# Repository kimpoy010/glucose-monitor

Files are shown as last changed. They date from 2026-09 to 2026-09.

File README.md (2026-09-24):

# Glucose Monitor (ESP32-C3, sweat + urine, DIY biosensor)

**⚠️ Not a medical device.** This is a research/educational electrochemical
biosensor rig. Sweat and urine glucose do NOT reliably track blood glucose
(see "Limitations" below). Do not use it to make insulin or treatment decisions.

## What this measures

Two independent electrochemical channels, each a 2-electrode amperometric
glucose oxidase (GOx) enzyme sensor read through a **discrete op-amp
transimpedance amplifier (TIA)** — no potentiostat AFE IC, no external ADC.
This is the cheapest working version of the build.

- **Sweat channel** — GOx electrode → op-amp TIA → ESP32-C3 ADC (GPIO0)
- **Urine channel** — GOx electrode → op-amp TIA → ESP32-C3 ADC (GPIO1)

The GOx enzyme oxidizes glucose and produces a small current proportional
(roughly, over a limited range) to glucose concentration. Each TIA converts
that current to a voltage the ESP32-C3's ADC can read directly.

## Hardware / BOM

| Part | Approx. cost | Notes |
|---|---|---|
| ESP32-C3 dev board | $3–5 | |
| 2x op-amp (LM358 or MCP6002, dual/single-supply, low bias current) | $0.30–1 each | one per channel |
| Feedback resistors (Rf, start ~100 kΩ–1 MΩ) | ~$1 | tune per electrode's current range |
| Bias divider resistors (2x per channel, e.g. 10 kΩ/10 kΩ off VCC) | ~$1 | sets working point at VCC/2 |
| Breadboard + jumper wires | $3–5 | |
| 2x GOx enzyme electrode/strip (salvaged from cheap glucose test strips, or bare screen-printed electrodes) | $0.20–0.50 each | working + reference/counter leads tied per the circuit below |
| SSD1306 0.96" I2C OLED (128x64) | $3–6 | displays both readings; shares the I2C bus (SDA/SCL) |

Total new spend: roughly **$11–20** if you don't already have a breadboard
and passive-component kit.

## Circuit (per channel)

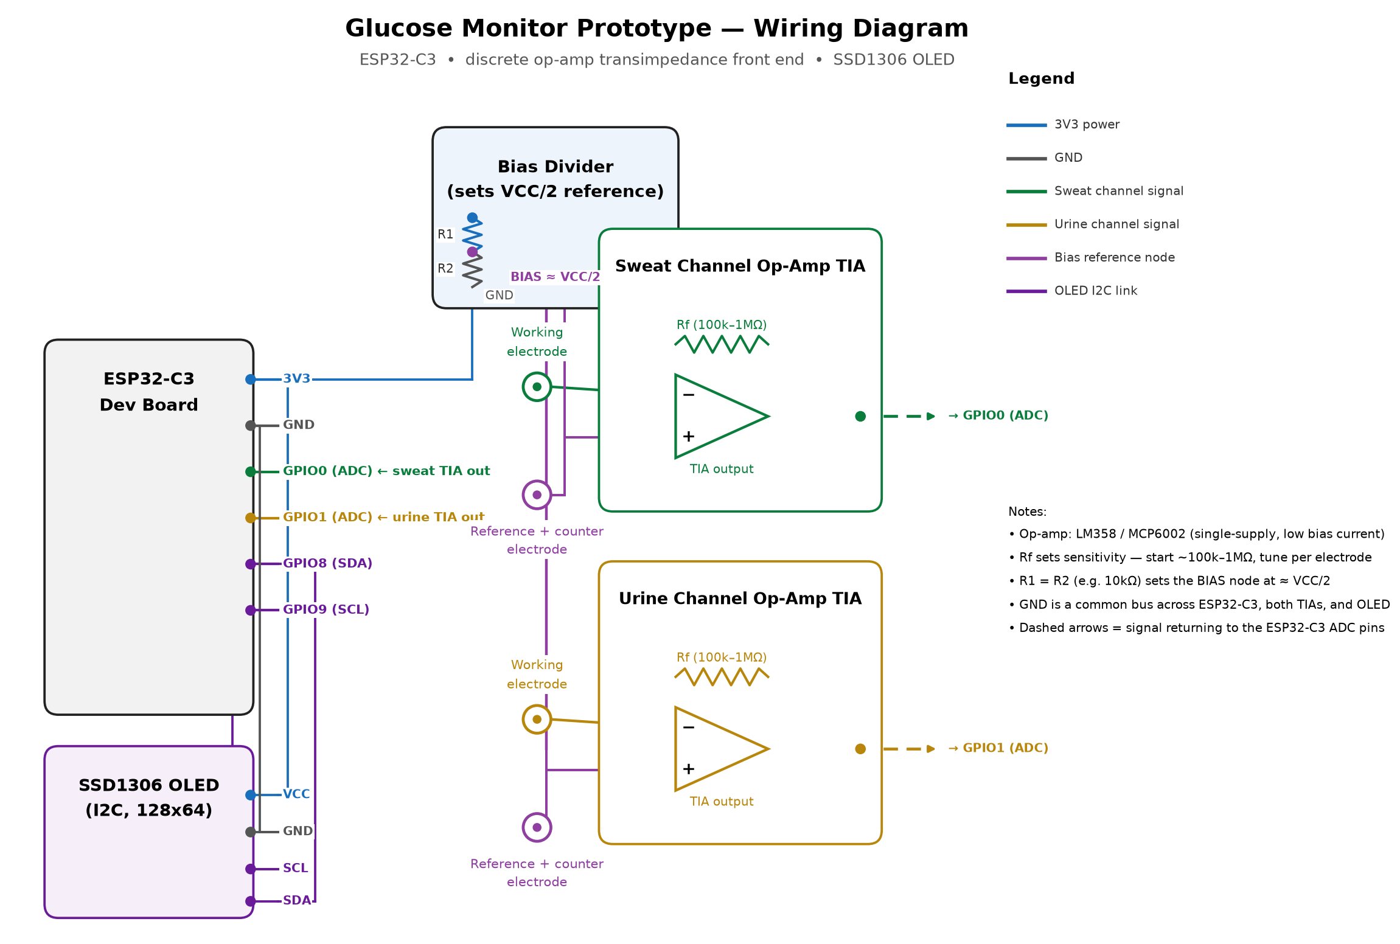
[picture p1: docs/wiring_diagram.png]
Wiring diagram


This is a 2-electrode cell — no active bias control loop like the
LMP91000/AD5940 provide, just a fixed bias voltage. Less stable and more
drift-prone than a real 3-electrode potentiostat, but it's what disposable
glucometers do internally, and it's essentially free.

1. Bias node: resistor divider from VCC (3.3V) to GND, midpoint ≈ VCC/2.
   Buffer it with a spare op-amp stage if you have one free, or just use it
   directly for low-current draw.
2. Reference + counter electrode leads → tied together → bias node.
3. Working electrode → op-amp **inverting** input (this is the TIA's virtual
   ground, held at the bias node's voltage by feedback).
4. Op-amp **non-inverting** input → bias node.
5. Feedback resistor **Rf** between op-amp inverting input and op-amp output.
6. Op-amp output → ESP32-C3 ADC pin (GPIO0 for sweat, GPIO1 for urine).

Start with Rf around 100 kΩ–1 MΩ; raise it if readings are too small to
resolve, lower it if the op-amp output saturates against VCC. Use a
low-bias-current, single-supply op-amp (LM358/MCP6002 are cheap and common)
so the tiny electrode current isn't swamped by the amp's own input current.

### OLED wiring

The SSD1306 shares the same I2C bus as everything else in this build:

- OLED `SDA` → ESP32-C3 GPIO8
- OLED `SCL` → ESP32-C3 GPIO9
- OLED `VCC` → 3.3V, `GND` → GND
- I2C address defaults to `0x3C` in `src/main.cpp` (`OLED_ADDR`) — some
  boards ship at `0x3D`; if the display stays blank, try that instead.

## Firmware

PlatformIO project targeting `esp32-c3-devkitm-1` (this is standard Arduino
C++ — `framework = arduino` — so it also works if you copy `src/main.cpp`
into an `.ino` sketch for the Arduino IDE; just rename it and install the
two libraries below via Library Manager).

Libraries (declared in `platformio.ini`, or install manually for Arduino IDE):
- `Adafruit SSD1306`
- `Adafruit GFX Library`

```
pio run -t upload
pio device monitor
```

The firmware oversamples each analog channel (64 reads averaged per sample,
see `OVERSAMPLE_COUNT` in `src/main.cpp`) to compensate for the native ADC's
noise and nonlinearity, since there's no external precision ADC in this
version. Every sample cycle it prints CSV over serial
(`mv_sweat,mg_dl_sweat,mv_urine,mg_dl_urine`) and refreshes the OLED with
both channels' voltage and (once calibrated) estimated mg/dL.

## Calibration (required, and the hard part)

`include/Calibration.h` holds a simple two-point linear map from TIA output
voltage to concentration. Out of the box it's a placeholder — you must:

1. Prepare known-concentration glucose standards (e.g. 0, 50, 100, 200 mg/dL
   in saline/artificial sweat or urine).
2. Apply each standard to the relevant electrode, let the reading settle,
   and record the millivolt output printed over serial.
3. Fill in `LinearCal::mvLow/concLow` and `mvHigh/concHigh` for each channel
   in `src/main.cpp`. Until you do, `apply()` returns NaN on purpose and the
   OLED/serial output shows "(uncalibrated)" instead of a fake number.

Enzyme electrodes drift and degrade — re-calibrate each time you swap
electrodes, and expect the linear range to be narrow (enzymatic sensors
saturate at higher concentrations). Expect more drift here than with an
active-bias AFE, since the 2-electrode cell has no feedback correcting the
bias voltage as the electrode ages.

## Limitations (read before you build)

- **2-electrode cell, no active bias control**: less stable and more prone
  to drift than a 3-electrode potentiostat (LMP91000/AD5940). Re-calibrate
  often, and don't expect long-term absolute accuracy.
- **Native ESP32-C3 ADC**: nonlinear at low voltages and noisier than a
  precision external ADC. Oversampling helps but doesn't fully fix this —
  if you need better resolution later, add back an ADS1115 on the ADC
  output (I2C) without changing the analog front end.
- **Urine glucose** only appears once blood glucose exceeds the renal
  threshold (~180 mg/dL). Below that, urine glucose reads ~zero regardless
  of blood glucose — it's a threshold indicator, not a continuous curve.
- **Sweat glucose** concentration is roughly 100x lower than blood glucose,
  lags it by several minutes, and is heavily confounded by sweat rate,
  contamination, and electrode fouling. Expect a relative trend signal at
  best, not an absolute number, without extensive per-session calibration
  against a real glucometer.

## Enclosure

A parametric, 3D-printable two-part case (base + OLED-window lid) is in
[`enclosure/`](enclosure/) -- see `enclosure/README.md` for print/assembly
instructions and the dimension assumptions to verify against your parts.

## Repo layout

```
platformio.ini        - build config, OLED library deps
include/Calibration.h - two-point linear calibration struct
src/main.cpp           - sampling loop, ADC oversampling, OLED display, pin config
enclosure/             - 3D-printable case (OpenSCAD source + STL exports)
```

## Upgrade path

If drift/noise becomes a problem, the cheapest single upgrade is usually:
add an ADS1115 (still just I2C, ~$6–10) reading the same TIA outputs
instead of the native ADC, before spending on a full potentiostat AFE IC
(LMP91000/AD5940).

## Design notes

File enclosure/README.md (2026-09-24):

# 3D-Printed Enclosure

Parametric OpenSCAD design for a two-part, screw-down enclosure: `base.stl`
(component box) + `lid.stl` (OLED window + cover). Edit `enclosure.scad`
and re-export if your parts differ from the assumptions below.

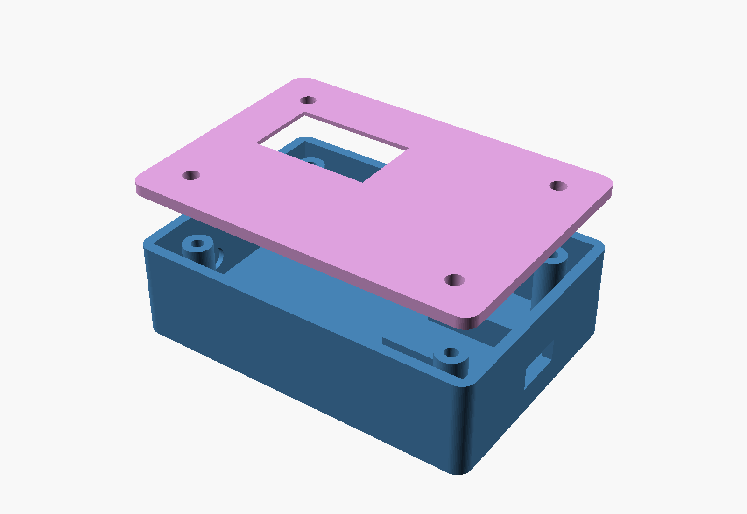
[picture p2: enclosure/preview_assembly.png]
Assembly preview


## Assumptions -- verify before printing

These dimensions are sized generously around the BOM parts, but breakout
board / module sizes vary by supplier. Measure your actual parts and edit
the variables at the top of `enclosure.scad` if anything doesn't fit:

- **ESP32-C3**: a "SuperMini"-style board, resting on two support ribs
  inside the box (friction fit + a dab of hot glue; adjust rib size/position
  to your exact board).
- **Sensor circuit**: a small perfboard with the op-amp channels, resistors,
  and bias divider -- fits in the remaining cavity space.
- **OLED**: generic 0.96" SSD1306 I2C module, ~29.5 x 29.5mm PCB, ~24 x 13mm
  visible display area. The lid has a flush recessed pocket for the PCB
  (module glues/tapes in from inside) plus a smaller through-window sized
  for the visible glass -- this avoids depending on exact mounting-hole
  positions, which vary a lot between suppliers.
- **USB-C cutout**: one short wall, generously sized (10.5 x 5mm) --
  check it lines up with your specific board's connector position.
- **Electrode wire feedthroughs**: two 5mm holes on the opposite short wall
  for the sweat/urine twisted-pair leads.

## Dimensions

- Internal cavity: 70 x 48 x 18mm (L x W x H)
- Wall thickness: 2.2mm
- Outer footprint: ~74.4 x 52.4mm, ~20.2mm base + 2.4mm lid

## Assembly

1. Print `base.stl` upright (open side up), no supports needed.
2. Print `lid.stl` flat, no supports needed.
3. Mount the ESP32-C3 on the support ribs, the sensor perfboard in the
   remaining floor space, and route the electrode leads out through the
   two wire holes.
4. Glue or tape the OLED module into the lid's recessed pocket, screen
   facing out through the window.
5. Wire the OLED and sensor board per the [wiring diagram](../docs/wiring_diagram.png).
6. Screw the lid down onto the base's 4 posts with M3 self-tapping screws
   (each post has a 2.6mm pilot hole; the lid has 3.4mm clearance holes).

## Regenerating STLs

Requires [OpenSCAD](https://openscad.org/).

```bash
openscad -o base.stl -D 'part="base"' enclosure.scad
openscad -o lid.stl  -D 'part="lid"'  enclosure.scad
```

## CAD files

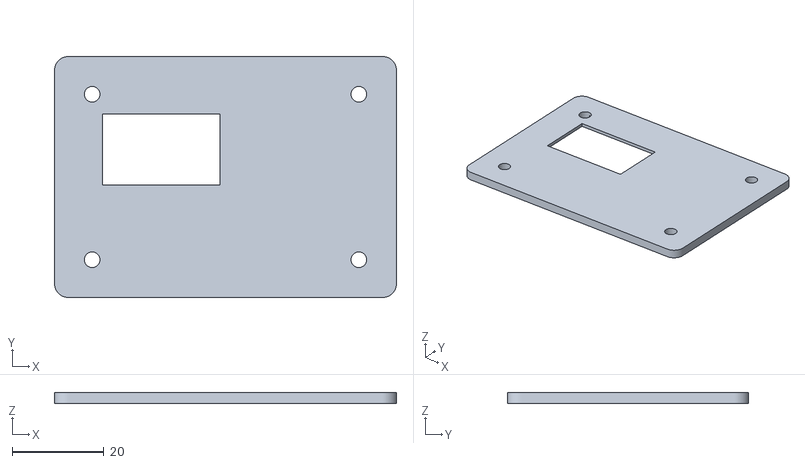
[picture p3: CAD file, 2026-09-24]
enclosure/lid.stl
74.4 x 52.4 x 2.40

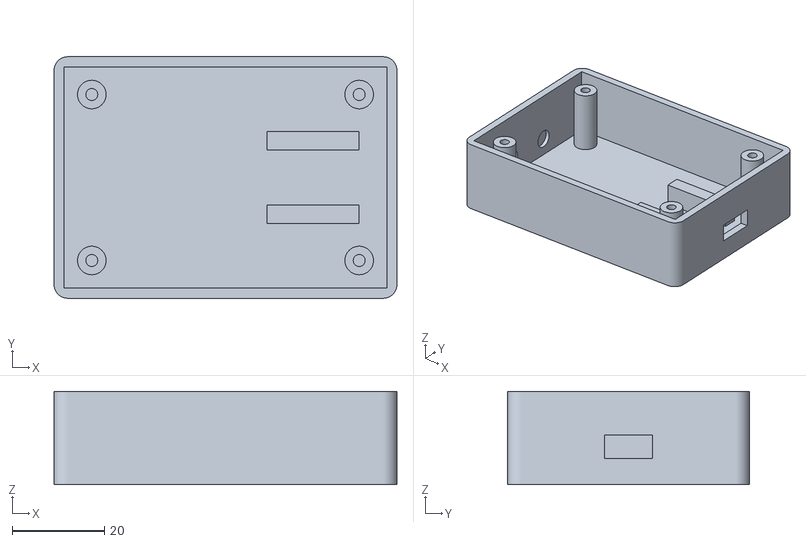
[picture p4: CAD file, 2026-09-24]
enclosure/base.stl
74.4 x 52.4 x 20.2

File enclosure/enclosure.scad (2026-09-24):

// Glucose Monitor Prototype -- 3D-printable enclosure
// Two parts: BASE (component box) + LID (OLED window, screws down onto BASE)
// FDM-friendly: no supports needed if printed as shown (base opening up, lid flat).
//
// ASSUMPTIONS -- verify against your actual parts before printing and adjust
// the variables below. Dimensions here are sized generously around:
//   - ESP32-C3 "SuperMini" style board (~23 x 18mm) mounted on two ribs
//   - a small universal perfboard/protoboard (~60 x 40mm) for the op-amp
//     channels, resistors, and bias divider
//   - a generic 0.96" SSD1306 I2C OLED module (~27-29mm square PCB,
//     ~24 x 13mm visible display area) -- these vary by supplier, so the
//     OLED pocket is a flush recess (module taped/glued in) rather than
//     relying on specific mounting-hole positions.
//   - USB-C port cutout on one short wall for charging/programming
//   - two 5mm wire feedthrough holes on the opposite wall for the
//     sweat/urine electrode lead pairs
//
// Render / export (also see build.sh):
//   openscad -o base.stl  -D 'part="base"' enclosure.scad
//   openscad -o lid.stl   -D 'part="lid"'  enclosure.scad
//   openscad -o preview.png -D 'part="assembly"' --camera=100,-100,90,0,0,0,0 --viewall enclosure.scad

part = "assembly"; // "base" | "lid" | "assembly" (preview only, do not print assembly)

// ---------------------------------------------------------------
// Core dimensions (mm) -- edit these to match your actual parts
wall        = 2.2;     // wall thickness
in_l        = 70;      // internal cavity length (X)
in_w        = 48;      // internal cavity width (Y)
in_h        = 18;      // internal cavity depth (Z), base only
lid_h       = 2.4;     // lid panel thickness
corner_r    = 3;       // outer corner rounding radius

// Screw posts (M3 self-tapping into PLA/PETG)
post_od       = 6.2;
post_pilot_d  = 2.6;   // pilot hole for M3 self-tap screw
post_inset    = 6;     // distance of post center from each internal corner
lid_hole_d    = 3.4;   // clearance hole in the lid for the M3 screw

// OLED pocket (flush recess in the lid, module glued/taped in from inside)
oled_pcb_w      = 29.5;
oled_pcb_h      = 29.5;
oled_pocket_d   = 1.4;    // pocket depth = PCB thickness, so the module sits flush
oled_window_w   = 25.5;   // cut all the way through, sized for the visible glass
oled_window_h   = 15.5;
oled_offset_x   = -14;    // OLED position relative to lid center (X)
oled_offset_y   = 6;      // OLED position relative to lid center (Y)

// USB-C cutout (short wall, +X side), sized with tolerance around the connector
usb_w = 10.5;
usb_h = 5.0;
usb_z = wall + 6;         // height of cutout center above the floor

// Electrode wire feedthroughs (short wall, -X side) -- one pair of holes
// per channel (sweat, urine), sized for a twisted-pair lead bundle
wire_hole_d = 5.0;
wire_hole_spacing = 14;

// ESP32-C3 mounting ribs (simple ledge, board rests on top and is held by
// friction / a dab of hot glue -- adjust rib positions to your exact board)
esp_rib_w = 4;
esp_rib_h = 6;           // rib height above floor
esp_rib_len = 20;
esp_pos_x = in_l/2 - 16;  // ribs placed toward the USB-C end
esp_pos_y = 0;

$fn = 64;

// ---------------------------------------------------------------
module rounded_box(l, w, h, r) {
    hull() {
        for (sx = [-1, 1]) for (sy = [-1, 1])
            translate([sx*(l/2 - r), sy*(w/2 - r), 0])
                cylinder(h=h, r=r);
    }
}

module screw_post(h) {
    difference() {
        cylinder(h=h, d=post_od);
        translate([0,0,-1]) cylinder(h=h+2, d=post_pilot_d);
    }
}

post_positions = [
    [ in_l/2 - post_inset,  in_w/2 - post_inset],
    [-in_l/2 + post_inset,  in_w/2 - post_inset],
    [ in_l/2 - post_inset, -in_w/2 + post_inset],
    [-in_l/2 + post_inset, -in_w/2 + post_inset],
];

// ---------------------------------------------------------------
module base() {
    out_l = in_l + wall*2;
    out_w = in_w + wall*2;
    out_h = in_h + wall;

    difference() {
        // outer shell (rounded_box already spans z=[0, out_h])
        rounded_box(out_l, out_w, out_h, corner_r);

        // hollow interior (open top)
        translate([0,0,wall + in_h/2 + 0.01])
            cube([in_l, in_w, in_h + 1], center=true);

        // USB-C cutout, +X wall
        translate([in_l/2 + wall/2, 0, usb_z])
            cube([wall + 2, usb_w, usb_h], center=true);

        // electrode wire feedthroughs, -X wall
        for (s = [-1, 1])
            translate([-in_l/2 - wall/2, s*wire_hole_spacing/2, wall + wire_hole_d/2 + 2])
                rotate([0,90,0])
                    cylinder(h=wall+2, d=wire_hole_d);
    }

    // screw posts (rise from floor)
    post_h = in_h - 1;
    for (p = post_positions)
        translate([p[0], p[1], wall])
            screw_post(post_h);

    // ESP32-C3 support ribs
    for (s = [-1, 1])
        translate([esp_pos_x, esp_pos_y + s*8, wall + esp_rib_h/2])
            cube([esp_rib_len, esp_rib_w, esp_rib_h], center=true);
}

// ---------------------------------------------------------------
module lid() {
    out_l = in_l + wall*2;
    out_w = in_w + wall*2;

    difference() {
        rounded_box(out_l, out_w, lid_h, corner_r);

        // OLED through-window (spans the full lid thickness, with margin
        // on both ends so the cut is clean at the top and bottom faces)
        translate([oled_offset_x, oled_offset_y, lid_h/2])
            cube([oled_window_w, oled_window_h, lid_h + 0.4], center=true);

        // OLED pocket, recessed from the INSIDE face (z=0, the face that
        // faces into the box) so the module glues in from inside with its
        // screen facing out through the window; the remaining lid_h-pocket_d
        // of material forms the visible outer bezel around the window.
        translate([oled_offset_x, oled_offset_y, oled_pocket_d/2])
            cube([oled_pcb_w, oled_pcb_h, oled_pocket_d + 0.2], center=true);

        // screw clearance holes
        for (p = post_positions)
            translate([p[0], p[1], -0.01])
                cylinder(h=lid_h + 0.2, d=lid_hole_d);
    }
}

// ---------------------------------------------------------------
if (part == "base") {
    base();
} else if (part == "lid") {
    lid();
} else {
    // assembly preview only -- export base.stl / lid.stl separately for printing
    color("SteelBlue") base();
    translate([0, 0, in_h + wall + 12])
        color("Plum") lid();
}

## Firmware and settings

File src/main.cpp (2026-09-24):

// ESP32-C3 dual-channel electrochemical glucose biosensor reader + OLED display.
// Bare-bones discrete version: no LMP91000/ADS1115 breakouts.
//
// Each channel is a 2-electrode amperometric cell (working + reference/counter
// tied together) feeding a discrete op-amp transimpedance amplifier (TIA):
//   working electrode -> op-amp inverting input (virtual ground)
//   feedback resistor Rf between op-amp inverting input and output
//   op-amp non-inverting input -> bias voltage (e.g. VCC/2 divider)
//   reference/counter electrodes -> same bias voltage node
//   op-amp output -> ESP32-C3 ADC pin
//
// A 128x64 SSD1306 I2C OLED displays both readings, refreshed each sample.
//
// This trades away the LMP91000's active bias control loop and the ADS1115's
// 16-bit resolution for near-zero extra hardware cost. The native ESP32-C3
// ADC is noisy and nonlinear, especially at low voltages -- this firmware
// leans on heavy oversampling to compensate, but expect more drift and less
// repeatability than the AFE-based version.
//
// IMPORTANT: readings are a relative electrochemical signal only until you
// run your own two-point calibration (see include/Calibration.h). Do not
// use this for medical decisions.

#include <Arduino.h>
#include <Wire.h>
#include <Adafruit_GFX.h>
#include <Adafruit_SSD1306.h>
#include "Calibration.h"

// ---- Analog channel pins (adjust to your wiring) ----
static constexpr int PIN_SWEAT_TIA_OUT = 0; // ADC1_CH0
static constexpr int PIN_URINE_TIA_OUT = 1; // ADC1_CH1

static constexpr int OVERSAMPLE_COUNT = 64; // averaged per reading to fight ADC noise

// ---- OLED (I2C, SDA/SCL) ----
static constexpr int PIN_SDA = 8;
static constexpr int PIN_SCL = 9;
static constexpr uint8_t OLED_ADDR = 0x3C; // common default; some boards are 0x3D
static constexpr int OLED_WIDTH = 128;
static constexpr int OLED_HEIGHT = 64;
Adafruit_SSD1306 display(OLED_WIDTH, OLED_HEIGHT, &Wire, -1);

// ---- Calibration (fill in from your own measurements) ----
LinearCal sweatCal;
LinearCal urineCal;

static constexpr uint32_t SAMPLE_INTERVAL_MS = 5000;
uint32_t lastSample = 0;

float readMillivoltsOversampled(int pin) {
    uint64_t sum = 0;
    for (int i = 0; i < OVERSAMPLE_COUNT; i++) {
        sum += analogReadMilliVolts(pin);
        delayMicroseconds(200);
    }
    return static_cast<float>(sum) / OVERSAMPLE_COUNT;
}

void updateDisplay(float sweatMv, float sweatConc, float urineMv, float urineConc) {
    display.clearDisplay();
    display.setTextSize(1);
    display.setTextColor(SSD1306_WHITE);

    display.setCursor(0, 0);
    display.println("Glucose Monitor (DIY)");
    display.drawLine(0, 10, OLED_WIDTH - 1, 10, SSD1306_WHITE);

    display.setCursor(0, 16);
    display.printf("Sweat: %.0f mV\n", sweatMv);
    display.setCursor(0, 28);
    if (isnan(sweatConc)) {
        display.println("  (uncalibrated)");
    } else {
        display.printf("  ~%.0f mg/dL\n", sweatConc);
    }

    display.setCursor(0, 42);
    display.printf("Urine: %.0f mV\n", urineMv);
    display.setCursor(0, 54);
    if (isnan(urineConc)) {
        display.println("  (uncalibrated)");
    } else {
        display.printf("  ~%.0f mg/dL\n", urineConc);
    }

    display.display();
}

void setup() {
    Serial.begin(115200);
    delay(500);

    analogReadResolution(12);
    analogSetPinAttenuation(PIN_SWEAT_TIA_OUT, ADC_11db); // full ~0-3.3V range
    analogSetPinAttenuation(PIN_URINE_TIA_OUT, ADC_11db);

    Wire.begin(PIN_SDA, PIN_SCL);
    if (!display.begin(SSD1306_SWITCHCAPVCC, OLED_ADDR)) {
        Serial.println("SSD1306 OLED not found -- check wiring/address");
    } else {
        display.clearDisplay();
        display.setTextSize(1);
        display.setTextColor(SSD1306_WHITE);
        display.setCursor(0, 0);
        display.println("Glucose Monitor");
        display.println("Warming up...");
        display.display();
    }

    Serial.println("mv_sweat,mg_dl_sweat,mv_urine,mg_dl_urine");
}

void loop() {
    uint32_t now = millis();
    if (now - lastSample < SAMPLE_INTERVAL_MS) return;
    lastSample = now;

    float sweatMv = readMillivoltsOversampled(PIN_SWEAT_TIA_OUT);
    float urineMv = readMillivoltsOversampled(PIN_URINE_TIA_OUT);

    float sweatConc = sweatCal.apply(sweatMv);
    float urineConc = urineCal.apply(urineMv);

    Serial.printf("%.1f,%.1f,%.1f,%.1f\n", sweatMv, sweatConc, urineMv, urineConc);
    updateDisplay(sweatMv, sweatConc, urineMv, urineConc);
}

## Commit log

2026-09-24 Scaffold ESP32-C3 dual-channel electrochemical glucose sensor project
    Adds PlatformIO firmware reading sweat (LMP91000 AFE) and urine (ADS1115)
    GOx electrochemical channels, a two-point calibration helper, and a README
    covering wiring, calibration steps, and the accuracy limitations of
    non-invasive sweat/urine glucose sensing.
    Claude-Session: https://claude.ai/code/session_01FJTeEa2fyEQGNaDPdh217v
2026-09-24 Switch to discrete op-amp analog front end and add SSD1306 OLED display
    Drops the LMP91000/ADS1115 breakout dependency in favor of a bare-bones
    2-electrode amperometric cell read through a discrete op-amp TIA on the
    native ESP32-C3 ADC, oversampled to reduce noise. Adds an SSD1306 I2C
    OLED to show both channels' voltage and calibrated concentration live.
    Calibration defaults now intentionally return NaN until real two-point
    values are filled in, so the display shows "(uncalibrated)" instead of a
    misleading number.
    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
    [main.cpp]
2026-09-24 Add wiring diagram for the discrete op-amp glucose sensor build
    Diagram covers the ESP32-C3, bias divider, both sweat/urine op-amp TIA
    channels with electrode connections, and the SSD1306 OLED I2C wiring.
    Linked from the README circuit section.
    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
2026-09-24 Add 3D-printable enclosure (OpenSCAD source + STL exports)
    Two-part screw-down case: base with ESP32-C3 mounting ribs, screw posts,
    USB-C cutout, and electrode wire feedthroughs; lid with a recessed OLED
    pocket and through-window. Parametric enclosure.scad so dimensions can be
    adjusted to match actual part sizes before printing.
    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
    [base.stl, enclosure.scad, lid.stl]
